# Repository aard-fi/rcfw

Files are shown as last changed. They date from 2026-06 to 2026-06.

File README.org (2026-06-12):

* NoTankS Arduino firmware                                            :TOC_4:
  - [[#introduction][Introduction]]
    - [[#working-features][Working features]]
      - [[#general][General]]
      - [[#notanks][NoTankS]]
    - [[#building][Building]]
    - [[#planned-features][Planned features]]
      - [[#general-1][General]]
      - [[#notanks-1][NoTankS]]
    - [[#required-hardware][Required hardware]]
      - [[#flysky-hardware][Flysky hardware]]
      - [[#elrs-hardware][ELRS hardware]]
  - [[#modified-parts][Modified parts]]
  - [[#rc-hardware][RC hardware]]
    - [[#pistol-grip-elrs-transmitter][Pistol grip ELRS transmitter]]
    - [[#elrs-transmitter][ELRS transmitter]]
    - [[#flysky-transmitter][Flysky transmitter]]
    - [[#6-channel-receivers][6 channel receivers]]
  - [[#arduino-shield][Arduino shield]]
  - [[#manual-wiring][Manual wiring]]
    - [[#led-groups][LED groups]]
    - [[#elrs-receiver-reset][ELRS receiver reset]]
    - [[#models][Models]]
      - [[#arctic-tinyrider][Arctic Tinyrider]]
      - [[#notanks-2][NoTanks]]
      - [[#rc-benchy][RC Benchy]]
  - [[#transmitter-channels][Transmitter channels]]
    - [[#default-channel-mapping-for-radiomaster-mt12][Default channel mapping for Radiomaster MT12]]
    - [[#default-channel-mapping-for-radiomaster-pocket][Default channel mapping for Radiomaster Pocket]]
    - [[#default-channel-mapping-for-flysky-fs-i6][Default channel mapping for Flysky FS-i6]]

** Introduction

This is a variant of my [[https://github.com/bwachter/arctic_tinyrider][Arctic Tinyrider controller firmware]], trying to support multiple models (including the original one) with compile time switches:

- the [[https://www.printables.com/model/114300-arctic-tinyrider-rc-snowmobile][Arctic Tinyrider RC snowmobile]]
- the [[https://www.thingiverse.com/thing:2789361][NoTankS tank]]
- the [[https://www.printables.com/model/34128-rc-benchy][RC Benchy]]

It should also work without changes for any model either just using two motors, ore one motor and one servo for steering - the upcoming model specific details are mostly about LED effects.

You can download pre-built firmware for all supported hardware and feature combinations from the [[https://github.com/aard-fi/rcfw/releases][releases page]] and flash them with [[https://github.com/avrdudes/avrdude][avrdude]] (=avrdude -p atmega328p|atmega4809 -c arduino|jtag2updi -P /dev/ttyS0 -b 115200=) , or follow the build instructions below.

Currently supported are the [[https://store.arduino.cc/products/arduino-nano][Arduino Nano]] and the [[https://store.arduino.cc/products/arduino-nano-every][Arduino Nano Every]] as well as all their clones - especially for the Nano I'd recommend getting a cheap clone (ideally with USB-C) via ebay or aliexpress.

The Every uses the first UART via USB serial, and the second UART via the RX/TX pins (which are used for connecting to the receiver). The older Nano connects its first (and only) UART to both USB serial and the RX/TX pins - so it should be programmed with the rest of the circuit powered down.

This is mostly annoying when actively developing - so for models which only occasionally get updated firmware without active development a generic Nano clone should be sufficient, and way cheaper. At the time of writing a Nano clone (which even has USB C) costs less than 1 EUR, while the original Every goes up to 20 EUR, with clones (which also stick to Micro USB for some reason) selling for roughly 12 EUR. Schematics and PCB layout for a shield offering all connections used by this project are in ./arduino-nano-shield/ - and can be [[https://www.pcbway.com/project/shareproject/rcfw_Arduino_Nano_shield_ea388a65.html][ordered via PCBWay]]. See below for build instructions.

The only other disadvantage of the original Nano for basic models is the lower serial port speed of 115200 - but that should not be an issue for the type of model this firmware tries to support. For ELRS receivers you may have to set their serial speed to 115200 once when using a Nano.

*** Working features
The initial version was written for IBUS receivers - some of the advanced features may not work with CRSF receivers yet.

**** General
- ignition switch: throttle is pinned to zero unless ignition switch is on. This allows somewhat safer handling when not fully switched off. A LED connected to D13 will signal throttle state by blinking (off) or solid light (on).
- throttle and steering (obviously)
- reversing, when supported by the model
- control remapping: a three state switch can be used to change controls. Exact functionality depends on model and transmitter used.
- dynamic speed control: a dial can be used to limit the speed without having to change the throttle curve in the transmitter. In the default setting the transmitter starts with 50% output, and can be set up to 100%. Exact functionality depends on model and transmitter used.
- failsafe requires the ability of the receiver to send sane values when connectivity has been lost. This works well with ELRS receivers, untested with Flysky, though it may be possible with some.
- three groups of LEDs can be used for models in the standard configuration: back/power, front and effect. Any of those LED groups can be set to an arbitrary number of pins from 0 to as many pins are available

Ignition switching, control remapping and dynamic speed control currently can be disabled at compile time to free up channels.

Flysky support will mostly be maintained at the current level, while new features target CRSF. Some rely on ELRS/CRSF behaviour, while others could be enabled somewhat easily for flysky as well. CRSF only features are:

- link detection on startup. The main program will only start running once link has been established
- receiver power cycling. With additional wiring (see below) the receiver can be power cycled on startup. This is recommended, as ELRS receivers go into WiFi configuration mode after some time, and would need manual intervention
- link monitoring with board reset after timeout, configurable at compile time
- remote type detection. With the controls for channel 4 in default position the type of remote (stick or pistol grip) can be auto-detected. This is a compile time setting, which defaults to on.

**** NoTankS
- turning based on accelerating or decelerating one side, depending on the current speed. This also allows turning at zero speed
- curves for low speed cutoff to keep the motors cooler

*** Building

Get the [[https://www.arduino.cc/en/software][Arduino IDE]], and the following libraries:

- the [[https://github.com/arduino-libraries/Servo][servo library]]
- for CRSF use [[https://github.com/AlfredoSystems/AlfredoCRSF][AlfredoCRSF]]
- for IBUS use [[https://github.com/bmellink/IBusBM][IBusBM]]

Configure the correct board (Nano or Nano Every are supported, Every recommended), and go through the defines at the beginning of the file to configure the build for your model and transmitter setup.

Alternatively you can install [[https://docs.arduino.cc/arduino-cli/][arduino-cli]], and use the included Makefile: =make deps= once, and then =make all-variants=, or =make= with the flags you want. See the Makefile for more details.

*** Planned features
**** General
- steering curve adjustment for controllers with two potis
- toggling ESC power supply/board power supply

**** NoTankS
- optimising the steering to result in as little speed change as possible

*** Required hardware

- one Arduino Nano Every
- one receiver
- one radio
- two ESCs with reverse which use the first PWM input value to configure the zero position. It also should be configurable for forward/reverse - most come in forward/reverse/brake configuration, and not all allow omitting the brake. I'm using the 160A variant from [[https://www.aliexpress.com/item/1005006256842555.html][here]].

**** Flysky hardware

Recommendation here is the FS-A8S as receiver, and an AFHDS 2a transmitter, like the FS-i6. When starting new I'd recommend going for ELRS hardware instead, though.

The main drawback of the FS-A8S is the lack of a second iBus - so we can't send custom telemetry data back to the radio. On the plus side it is a tiny receiver, very cheap (roughly 10 EUR), and can output up to 18 channels via iBus. I'm not aware of receivers of a similar size with more than one iBus - other small Flysky receivers just have more connectors for PWM breakout cables, which we don't need as we're controlling that part via the Arduino.

**** ELRS hardware

Any ELRS transmitter should do, if you're looking for recommendations:

- for a pistol grip style one, Radiomaster MT12
- for a traditional drone/plane one, Radiomaster Boxer M2, or if you want to be fancier, the TX16S
- for a small, more portable one, Radiomaster Pocket

For receivers any of the compact (nano) receivers should be fine, from any manufacturer - as far as I'm aware all of them have RX/TX ports for CRSF. Some of the larger ones do not have that - but the tiny ones are easier to stuff into models anyway.

Main drawbock of ELRS is that the receivers are roughly double the price of AFHDS ones - but for that we always have the ability to send telemetry back.

** Modified parts
For some of the models I've modified parts. You can find those in separate repositories:

- [[https://github.com/bwachter/arctic_tinyrider][Arctic Tinyrider]]
- [[https://github.com/bwachter/notanks/][NoTankS]]

** RC hardware

Both throttle curve and trim settings will change the values sent by the transmitter. Currently the assumption is that for our models we can adjust those settings on the Arduino, so adjusted input may be improperly handled - don't use that.

*** Pistol grip ELRS transmitter
With the default setup of steering at channel 1 and throttle at channel two basic control will work out of the box.

Remapping of throttle and steering is not supported as it does not make much sense with that style of transmitter.

The ignition switch is expected on channel 9.

*** ELRS transmitter
This setup is currently untested, but should be working.

The ignition switch is expected on channel 5, which should be one of the two-state switches in the default configuration.

*** Flysky transmitter
At least the FS-i6 requires extra setup for the switches, see the transmitter section below for details.

The ignition switch is expected on channel 7.

*** 6 channel receivers

VRB is currently not used, so to make this work you need to select three features to drop to free up channels, and disable them at compile time. With ELRS receivers supporting at least 16 channels, and all the cheap AFHDS nano receivers supporting 10 support for running building with less than 10 channels may be dropped eventually.

** Arduino shield

The included Arduino shield simplifies the wiring a lot - see the next section if you prefer manual wiring.

#+CAPTION: Three PCB versions, left to right V1, V2 and V2.1
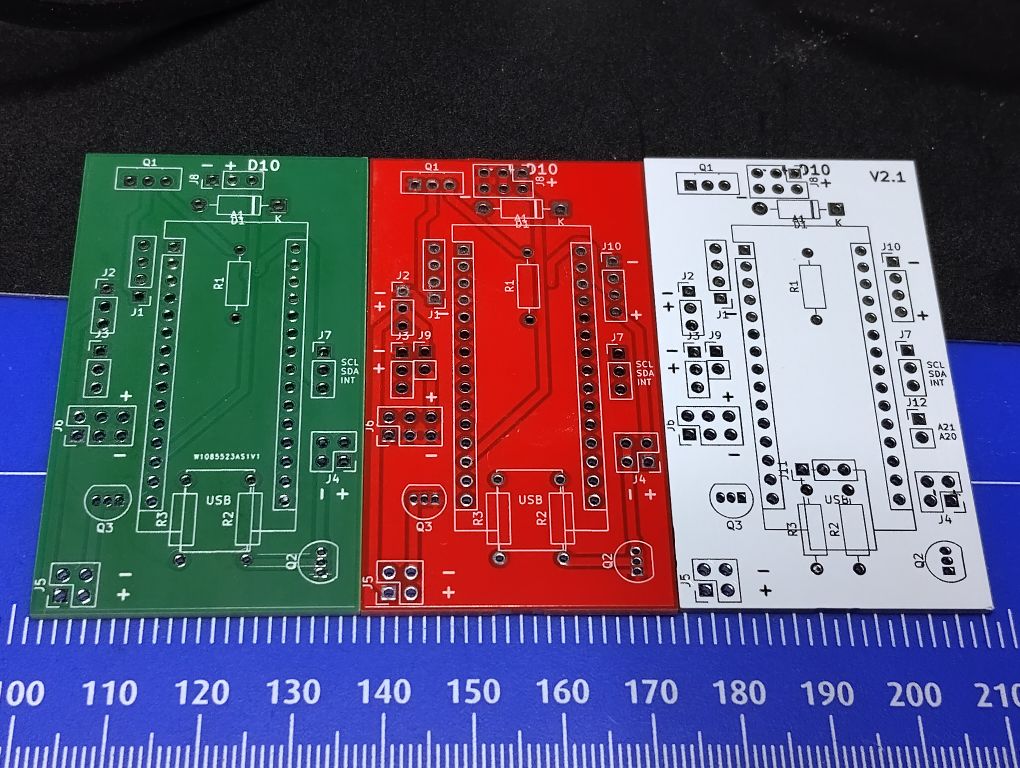
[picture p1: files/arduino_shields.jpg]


If you want the receiver controllable via the Arduino solder a 1kΩ resistor into =R1=, and a  =BD139= or compatible transistor into =Q1=. If you don't need that just bridge pins 1 and 2 of =Q1=.

If you want LEDs solder =2N3904= or compatible transistors into =Q2= and =Q3=, and 4.7kΩ resistors into =R2= and =R3=. If your LEDs are 5V tolerant you can just bridge =R2/R3= instead. Solder pin headers into =J4= and =J5= - each can support two connections.

To prevent the Arduino powering the ESC and motors when only plugged in via USB solder a diode into =D1=. This can be bridged in case you'd rather just be careful, and buy more Arduinos when you mess up.

For the ELRS connector, solder a 4 pin header into =J1=.

For one ESC, solder one 3 pin header into =J2=. This will power the circuit when on battery. For a second ESC, also solder one 3 pin header into =J3=. The power connector from this leads to =J6= - if you want to power extra devices not controlled from the Arduino solder a 6 pin header into that one.

For the servo solder a 3 pin header into =D10=. In case you need two servos, but only one ESC also populate J3, and add a wire bridge from the middle pin of =J3= to the middle pin of =J2= - this will connect the otherwise isolated power pin of =J2/J6=.

To make I²C accessible solder a 3 pin header into =J7=.

The V2 version (included here, but not yet available for order) includes some conveniences for some model:

- the servo header =D10= can be populated with a 3x2 pin header, allowing to plug in two servos. This is useful for the RC benchy to move the steering wheel as well
- a jumper was added between voltage pins of the two ESC headers =J2/J3=. This allows easy power connection for single ESC models, either by jumper or permanent bridge
- a 4 pin header with Arduino pins =D5= and =D6= got added with a common GPS footprint, for use via software serial, though may be useful for extra pins on some other models as well

The V2.1 version adds:

- a three pin header behind the LED resistors over =D11/D12/D13= to allow easy connection of a =74HC595D= module for adding more LEDs
- pin headers on =A20= and =A21= and for future expansions

** Manual wiring

You'll need one power and one ground bar to connect everything to. A quick and dirty variant is getting ready made jumper wires, cut them and then twist end solder the ends together. On the Arduino connect ground and VIN to ground/power bars via a diode to make sure components can't draw power through the Arduino if it is the only thing powered, like during flashing.

The Pins are set up to minimise gaps, soldering three three-pin-headers will cover all pins on one side of the Arduino, while connecting the unused RST pin. On the other side just VIN and D13 need to be populated.

On setups with two or more ESCs make sure to only connect the power pin of one of them.

Nano receivers should have dedicated ground and power connectors either in the header or cable - in that case just connect all of them. For other receivers connect the bus, and take ground and power from any other channel.

The following sections contain tables with the pinouts, with the table colums ordered according to the pinout of the component cables.

IBUS receivers have three pin connectors, and only connect to RX. CRSF receivers have four pin connectors, and also connect to TX. The pinouts are for the Arduino Nano Every - on the Nano use RX/TX instead. Note that flashing on the Nano uses RX/TX, so for that board RX should be disconnected on during flashing.

*** LED groups

The Arduino can tolerate about 20mA per pin, with a total of 200mA. One bright 5mm LED draws roughly 20mA - so three sets of two LEDs should be safe to connect directly. For ad-hoc cabling it is sensible to provide a ground pin to connect to a separate ground bar for additional LEDs. When switching LEDs via a transistor it also makes sense to create a power bar.

With insufficient pins, or more/brighter LEDs they should be wired via a transistor. For a small NPN transistor like the 2N3904 you'd connect the base to the Arduino pin through a 4.7kΩ resistor, emitter to GND, and the LED between VCC and the collector.

The default LED pins are in this table:

|             | Pin 1 | Pin 2 |
|-------------+-------+-------|
| status/back | D13   | D2    |
| front       | D11   | D12   |
| effect      | D4    | D5    |

Pin 2 is only relevant when attaching two power hungry LEDs directly for one specific effect, and may have to be explicitly enabled for a specific model.

If a model doesn't incorporate LEDs one status LED should still be visible for safety reasons. This can either be achieved by mounting the Arduino in a way that the on board LED connected to pin 13 becomes visible, or by connecting an extra LED to pin 13.

When incorporating LEDs into a model the status LEDs should be used as the rear lights.

*** ELRS receiver reset

Pin A7 is configured as digital pin, and pulled high on startup. This allows powering the receiver only when the program is running, and power cycling it as needed.

To use this you'll need a NPN transistor like the BD139. Connect the base to A7 through a 1kΩ resistor, emitter to GND, collector to GND of the receiver, and  of the power in of the receiver to VCC.

*** Models
**** Arctic Tinyrider

|          | GND | 5v | arduino | arduino |
|----------+-----+----+---------+---------|
| ESC      | x   | x  | D3      |         |
| receiver | x   | x  | RX1     | TX1     |
| arduino  | x   | x  |         |         |
| servo    | x   | x  | D10     |         |

**** NoTanks

|           | GND | 5v | arduino | arduino |
|-----------+-----+----+---------+---------|
| left ESC  | x   | x  | D3      |         |
| right ESC | x   | x  | D4      |         |
| receiver  | x   | x  | RX1     | TX1     |
| arduino   | x   | x  |         |         |

**** RC Benchy

|          | GND | 5v | arduino | arduino |
|----------+-----+----+---------+---------|
| ESC      | x   | x  | D3      |         |
| receiver | x   | x  | RX1     | TX1     |
| arduino  | x   | x  |         |         |
| servo    | x   | x  | D10     |         |

** Transmitter channels
This section contains tables about channel setups for all tested transmitters, with information on how to set up additional switches, if needed.

*** Default channel mapping for Radiomaster MT12

| Channel | Trigger  | Type            | Comments                               |
|---------+----------+-----------------+----------------------------------------|
|       1 | wheel    |                 |                                        |
|       2 | throttle |                 |                                        |
|       3 | SA       | switch, 3 state | default 1000                           |
|       4 | SB       | button          | default 1000, starts timer per default |
|       5 | P1       | poti            | default 1500                           |
|       6 | P2       | poti            | default 1500                           |
|       7 | SC       | button, 2 state | default 1000                           |
|       8 | SD       | button, 2 state | default 1000                           |

Note that channel 5 for ELRS is typically a 1 bit channel for arming - and as such the first poti mapped to channel 5 is not ideal. This firmware assumes that it got remapped to channel 5, and the expansion module with the two switches got installed and mapped, leading to the following configuration:

| Channel | Trigger  | Type            | Comments                               |
|---------+----------+-----------------+----------------------------------------|
|       1 | wheel    |                 |                                        |
|       2 | throttle |                 |                                        |
|       3 | SA       | switch, 3 state | default 1000                           |
|       4 | SB       | button          | default 1000, starts timer per default |
|       5 | FL1      | switch, 2 state | default 1000, expansion module (front) |
|       6 | P2       | poti            | default 1500                           |
|       7 | SC       | button, 2 state | default 1000                           |
|       8 | SD       | button, 2 state | default 1000                           |
|       9 | P1       | poti            | default 1500                           |
|      10 | FL2      | switch, 2 state | default 1000, expansion module (back)  |

To configure the expansion module

- go to hardware settings, and set S3/S4 to =switch=
- scroll down, and set =FL1= to =S3=, =FL2= to =S4=, both with =2POS=
- go to model settings, mixes page, and change channel 5 to FL1, add channel 9 with S1, and add channel 10 with FL2

*** Default channel mapping for Radiomaster Pocket

| Channel | Trigger                 | Type            | Comments     |
|---------+-------------------------+-----------------+--------------|
|       1 | right stick, left/right |                 |              |
|       2 | right stick, up/down    |                 |              |
|       3 | left stick, up/down     |                 | default 1000 |
|       4 | left stick, left/right  |                 |              |
|       5 | SA                      | switch, 2 state | default 1000 |
|       6 | SB                      | switch, 3 state | default 1000 |
|       7 | SC                      | switch, 3 state | default 1000 |
|       8 | SD                      | switch, 2 state | default 1000 |
|       9 | SE                      | button, 2 state | default 1000 |
|      10 | SI                      | poti            | default 1000 |

*** Default channel mapping for Flysky FS-i6

| Channel | Trigger                 | Type            | Comments     |
|---------+-------------------------+-----------------+--------------|
|       1 | right stick, left/right |                 |              |
|       2 | right stick, up/down    |                 |              |
|       3 | left stick, up/down     |                 | default 1000 |
|       4 | left stick, left/right  |                 |              |
|       5 | VRA                     | poti            | default 1000 |
|       6 | VRB                     | poti            | default 1000 |
|       7 | SWA                     | switch, 3 state | default 1000 |
|       8 | SWB                     | switch, 2 state | default 1000 |
|       9 | SWC                     | switch, 2 state | default 1000 |
|      10 | SWD                     | switch          | default 1000 |

VRA/VRB are configured on channels 5/6 per default in 'aux channel setup', while the switches are not assigned.

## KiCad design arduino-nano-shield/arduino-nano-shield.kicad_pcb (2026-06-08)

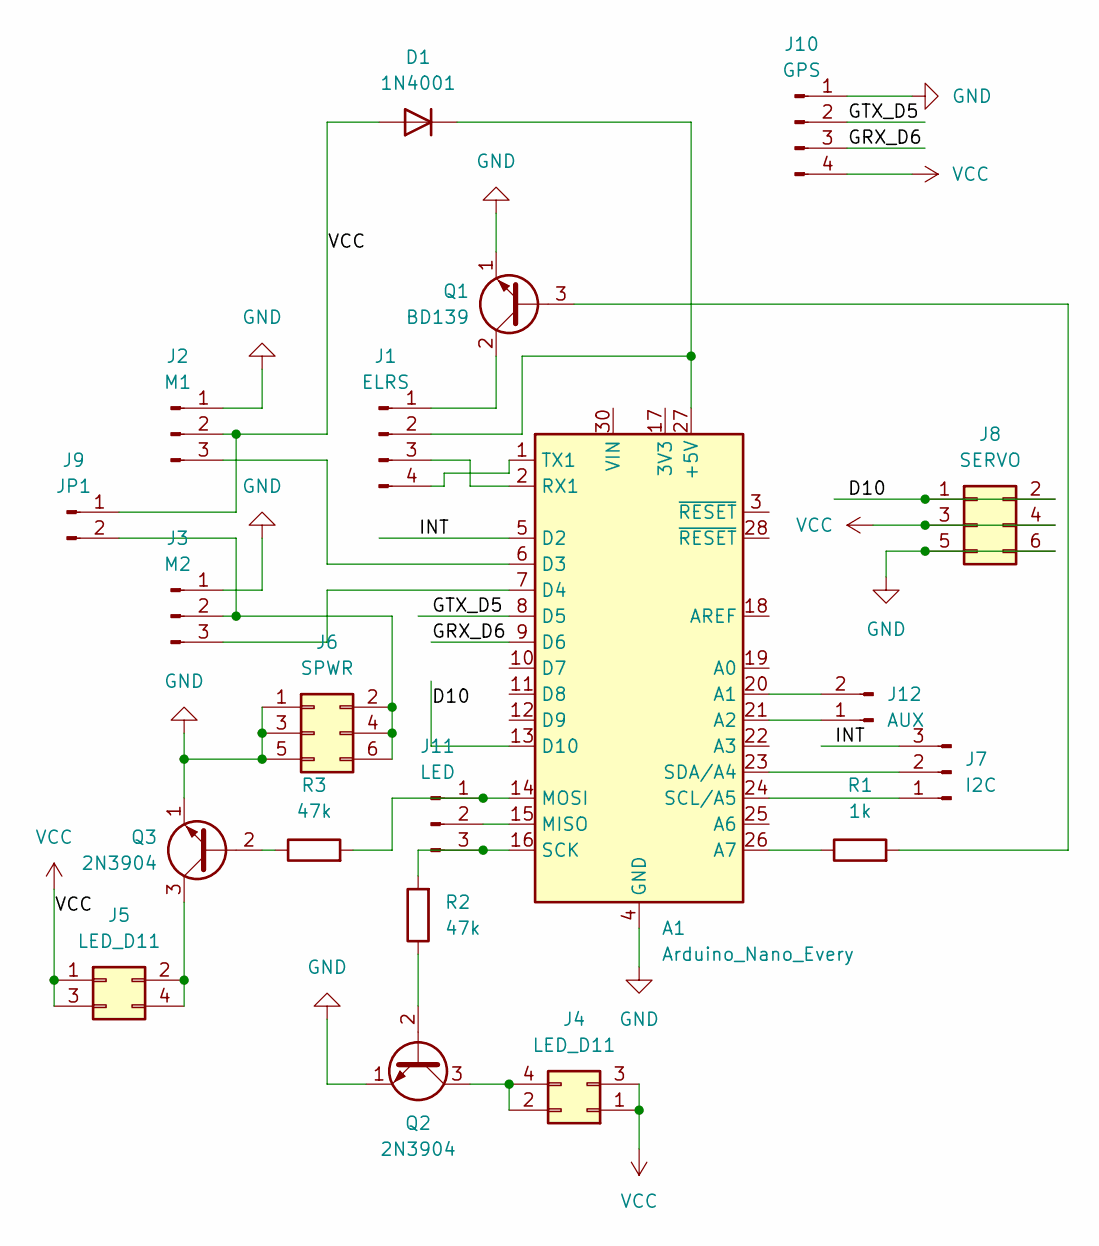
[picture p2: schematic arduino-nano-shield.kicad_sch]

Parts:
A1: Arduino_Nano_Every; Arduino_Nano
D1: 1N4001; D_DO-41_SOD81_P10.16mm_Horizontal
J1: ELRS; PinHeader_1x04_P2.54mm_Vertical
J2: M1; PinHeader_1x03_P2.54mm_Vertical
J3: M2; PinHeader_1x03_P2.54mm_Vertical
J4, J5: LED_D11; PinHeader_2x02_P2.54mm_Vertical
J6: SPWR; PinHeader_2x03_P2.54mm_Vertical
J7: I2C; PinHeader_1x03_P2.54mm_Vertical
J8: SERVO; PinHeader_2x03_P2.54mm_Vertical
J9: JP1; PinHeader_1x02_P2.54mm_Vertical
J10: GPS; PinHeader_1x04_P2.54mm_Vertical
J11: LED; PinHeader_1x03_P2.54mm_Vertical
J12: AUX; PinHeader_1x02_P2.54mm_Vertical
Q1: BD139; TO-126-3_Vertical
Q2, Q3: 2N3904; TO-92_Inline
R1: 1k; R_Axial_DIN0207_L6.3mm_D2.5mm_P10.16mm_Horizontal
R2, R3: 47k; R_Axial_DIN0207_L6.3mm_D2.5mm_P10.16mm_Horizontal

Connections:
/D10: A1.13 (D10), J8.1, J8.2
/GRX_D6: A1.9 (D6), J10.3
/GTX_D5: A1.8 (D5), J10.2
/INT: A1.5 (D2), J7.3
GND: A1.4 (GND), A1.29 (GND), J2.1, J3.1, J6.1, J6.3, J6.5, J8.5, J8.6, J10.1, Q1.1 (E), Q2.1 (E), Q3.1 (E)
unnamed: A1.27 (+5V), D1.1 (K), J1.2
unnamed: A1.20 (A1), J12.2
unnamed: A1.21 (A2), J12.1
unnamed: A1.26 (A7), R1.1
unnamed: A1.6 (D3), J2.3
unnamed: A1.7 (D4), J3.3
unnamed: A1.15 (MISO), J11.2
unnamed: A1.14 (MOSI), J11.1, R3.2
unnamed: A1.2 (RX1), J1.3
unnamed: A1.16 (SCK), J11.3, R2.2
unnamed: A1.24 (SCL/A5), J7.1
unnamed: A1.23 (SDA/A4), J7.2
unnamed: A1.1 (TX1), J1.4
unnamed: J1.1, Q1.2 (C)
unnamed: J3.2, J6.2, J6.4, J6.6, J9.2
unnamed: J4.2, J4.4, Q2.3 (C)
unnamed: J5.2, J5.4, Q3.3 (C)
unnamed: Q1.3 (B), R1.2
unnamed: Q2.2 (B), R2.1
unnamed: Q3.2 (B), R3.1
VCC: D1.2 (A), J2.2, J4.1, J4.3, J5.1, J5.3, J8.3, J8.4, J9.1, J10.4

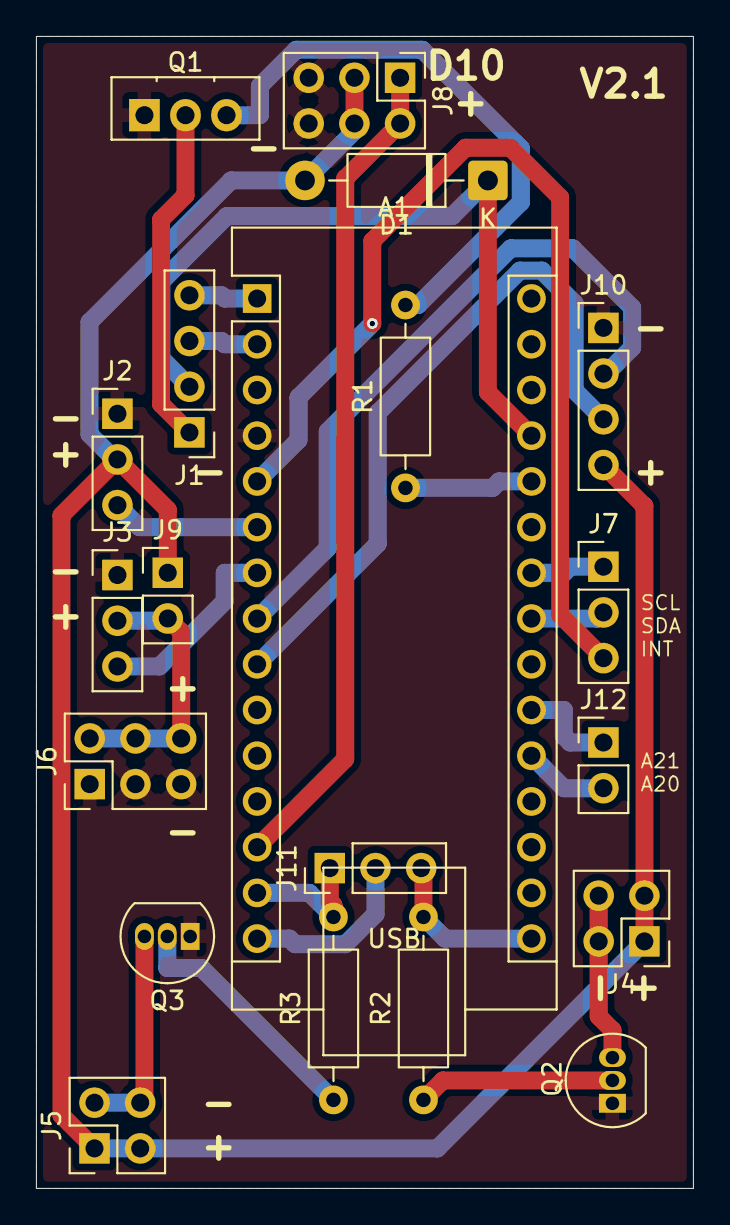
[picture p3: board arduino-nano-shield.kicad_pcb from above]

Board: 2 copper layers, 36.5 x 64.0 mm, 20 parts (0 on the bottom side), 26 nets.

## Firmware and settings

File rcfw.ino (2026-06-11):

// See LICENSE.txt or https://creativecommons.org/licenses/by-nc-sa/4.0/
#include <Servo.h>
#include <avr/wdt.h>

#define SNOW_MOBILE 1
#define RC_BENCHY 2
#define NOTANK 3

#define LED_MODE_DIRECT 1
#define LED_MODE_74HC595D 2
#define LED_MODE_ADDRESSABLE 3

// set this to the LED mode you're using from above list
// when not using any LEDs any value here is fine
#define LED_MODE LED_MODE_74HC595D

// set this to the model you're using from above list
#ifndef RC_MODEL
#define RC_MODEL NOTANK
#endif

struct channel_mapping {
    int control_channel;
    int ignition_channel;
    int effect_channel;
    int speed_channel;
};

// if we have no idea what the remote control is just disable
// all the fancy extra channels
const channel_mapping default_mapping = {
  .control_channel = -1,
  .ignition_channel = -1,
  .effect_channel = -1,
  .speed_channel = -1
};

const channel_mapping flysky_st_mapping = {
  .control_channel = 8,
  .ignition_channel = 7,
  .effect_channel = 6,
  .speed_channel = 5
};

const channel_mapping radiomaster_st_mapping = {
  .control_channel = 7,
  .ignition_channel = 5,
  .effect_channel = -1,
  .speed_channel = 10
};

const channel_mapping radiomaster_pg_mapping = {
  .control_channel = -1,
  .ignition_channel = 5,
  .effect_channel = -1,
  .speed_channel = 6
};

// I do not have a pistol grip FlySky transmitter - the first entry is a placeholder in case someone
// wants to contribute that.
//
// The generic manufacturer types are used for type auto detection. For the Radiomaster ones we can
// use channel 4 to check the type: PG has it at 1000 as default, while stick has it at 1500.
#define FLYSKY_PG 1
#define FLYSKY_ST 2
#define FLYSKY 3
#define RADIOMASTER_PG 4
#define RADIOMASTER_ST 5
#define RADIOMASTER 6

// select the type of transmitter from above list. For pistol grip style transmitters
// the first two channels should be the same, no matter the manufacturer. For stick style
// transmitters the first four channels should be the same - so basic functionality should
// work by just selecting a matching type.
//
// for extra functionality involving the switches and potis receiver specific configuration
// may be required
#ifndef TX_TYPE
#define TX_TYPE RADIOMASTER
#endif

// this must match the configured speed in the receiver
// if the connection does not work double check that the receiver is configured
// correctly. This is particularly important on the original Nano, which can
// only reliably sustain serial speeds of up to 115200 - for other boards our
// default should match the receiver default.
#ifdef ARDUINO_AVR_NANO
#define CRSF_SPEED 115200
#else
#define CRSF_SPEED 420000
#endif

// set this for logging complete channel status table (CRSF only)
//#define DEBUG_CHANNELS 1

// remove this to skip all debug messages. Note that the Nano already
// doesn't log due to the single serial port.
#define DEBUG_MESSAGES 1

/*
 The further you go down the defines the less likely you should
 want to change something.

 PWM motor ranges are based on the servo library, ranging from 0 to 180 - not
 the native 0-255 of Arduino PWM (which is a wrong frequency)..
*/

// this is the slowest supported motor speed - everything lower and we'll
// disable the motor to avoid them burning out
#define PWM_CUTOFF 10

// the digital pin the motor is attached to
#if RC_MODEL == NOTANK
#define MOTOR_PIN_LEFT 3
#define MOTOR_PIN_RIGHT 4
#elif RC_MODEL == RC_BENCHY
#define MOTOR_PIN 3
#define SERVO_PIN 10
#elif RC_MODEL == SNOW_MOBILE
#define MOTOR_PIN 3
#define SERVO_PIN 10
#endif

// Helpers for LED array definitions.  In direct mode only LED() is usable.
#define LED(n)     (n)           // single-colour LED on pin or output n
#define RGB(n)     (-(n) - 2)    // RGB on outputs n(R), n+1(G), n+2(B). n >= 0.
#define RGBW(n)    (-(n) - 1002) // RGBW on outputs n(R), n+1(G), n+2(B), n+3(W). n >= 0.

// LED definitions must end with -1 as end of array marker to support
// variable amounts of LED pins depending on model.
//
// The power LEDs also serve as rear lights.
//
// Encoding (see also LED(), RGB(), RGBW() macros):
//   positive value (0, 1, 2 …)   = single-colour LED on that pin/index.
//   negative value -2 … -999     = RGB LED.  Base index = abs(value) - 2.
//   negative value -1002 …       = RGBW LED. Base index = abs(value) - 1002.
//   -1                           = end of array.
// Examples:    5  -> single LED on pin/index 5
//             -2  -> RGB on pins/indices 0(R), 1(G), 2(B)
//             -5  -> RGB on pins/indices 3(R), 4(G), 5(B)
//          -1002  -> RGBW on pins/indices 0(R), 1(G), 2(B), 3(W)
//          -1005  -> RGBW on pins/indices 3(R), 4(G), 5(B), 6(W)
#if LED_MODE == LED_MODE_DIRECT
#define POWER_LEDS {2,13,-1}
#if RC_MODEL == NOTANK
#define POWER_LEDS {13,-1}
#define FRONT_LEDS {11,-1}
#define EFFECT_LEDS {-1}
#else
#define FRONT_LEDS {11,12,-1}
#define EFFECT_LEDS {4,5,-1}
#endif

#elif LED_MODE == LED_MODE_74HC595D
const int data_pin = 11; // LDSI
const int latch_pin = 12; // LDSTR
const int clock_pin = 13; // LDSCK

// LED indices in the 24-bit shift register chain (3x 74HC595D).
// Each logical LED group is tied to one physical chip for clean wiring:
//   Chip 1 (outputs 0-7):   Rear / power LEDs
//   Chip 2 (outputs 8-15):  Front LEDs
//   Chip 3 (outputs 16-23): Effect LEDs
//
// Use LED() for single-colour outputs, RGB() for RGB triples, RGBW() for RGBW.
// RGB() or RGBW() definitions still work with on/off commands, as those trigger
// all possible outputs.
#define POWER_LEDS  { RGB(0), -1 }   // outputs 0(R), 1(G), 2(B)  – first chip
#define FRONT_LEDS  { RGB(8), -1 }   // outputs 8(R), 9(G), 10(B) – second chip
#define EFFECT_LEDS { LED(16), -1 }  // output 16                 – third chip

#elif LED_MODE == LED_MODE_ADDRESSABLE
// placeholder for addressable LED pin/index definitions
#endif

/*
This is the default speed curve for dynamic speed adjustment, which allows adjusting from
0% to 100%, on a model which does have reversing. Adjusting it is not tested, though, and
may need somewhat more complicated speed calculations: currently models which support
speed adjustment just start at min-45 and max-45, and add those speed adjustments in, which
expands to the whole range.
*/
#define SPEED_MIN -45
#define SPEED_MAX 45

// The receiver should be connected to this pin via a NPN transistor to enable
// power cycling it when the Arduino restarts. With ELRS receivers and binding
// phrases this allows easy switching of controllers during play without having
// to touch the model
#define POWER_PIN_RCV A7
#define POWER_PIN A6

// time LED should remain in a specific status. This is per loop - so
// take LOOP_DELAY into account as well.
#define LED_DELAY 10
// slightly delays the loop to allow time for mechanical elements to
// move, at cost of slight input delay.
#define LOOP_DELAY 20

#define DEBUG_DELAY 10

#define PWM_MIN 0
#define PWM_MID 90
#define PWM_MAX 180

#define PWM_STOP 90

#define STEER_MIN 0
#define STEER_MID 90
#define STEER_MAX 180

// with trim the values sent by the transmitter might be over/under this range,
// but this is good enough for now
#define RX_MIN 1000
#define RX_MID 1500
#define RX_MAX 2000

#define RX_TOLERANCE 30

#define TX_IBUS 1
#define TX_CRSF 2

#if TX_TYPE <= FLYSKY
#define SERIAL_PROTOCOL TX_IBUS
#else
#define SERIAL_PROTOCOL TX_CRSF
#endif

#if SERIAL_PROTOCOL == TX_CRSF
// defines how many loop cycles we wait when link has been lost before
// resetting.
#define LINK_DOWN_DELAY 1000
#endif

#if SERIAL_PROTOCOL == TX_IBUS
#include <IBusBM.h>
IBusBM IBus;
#elif SERIAL_PROTOCOL == TX_CRSF
#include <AlfredoCRSF.h>
AlfredoCRSF crsf;
#endif

#if RC_MODEL == NOTANK
Servo motor_left;
Servo motor_right;
#elif RC_MODEL == RC_BENCHY
Servo motor;
Servo steering;
#elif RC_MODEL == SNOW_MOBILE
Servo motor;
Servo steering;
#endif
int ignition=RX_MIN;
int led_state=0;
int debug_state=0;
#ifdef LINK_DOWN_DELAY
int linkdown_state=0;
#endif
int throttle_channel;
int steering_channel;

int power_leds[]=POWER_LEDS;
int front_leds[]=FRONT_LEDS;
int effect_leds[]=EFFECT_LEDS;

enum led_effects{
  led_off   = 0x00,
  led_r     = 0x01,  // bit 0
  led_g     = 0x02,  // bit 1
  led_b     = 0x04,  // bit 2
  led_w     = 0x08,  // bit 3
  led_on    = 0x0F,  // r | g | b | w
  led_cycle = 0x10,  // bit 4 – OR with any colour for blink
};

channel_mapping get_tx_mapping(int type){
  switch(type){
    case FLYSKY_ST: return flysky_st_mapping;
    case RADIOMASTER_ST: return radiomaster_st_mapping;
    case RADIOMASTER_PG: return radiomaster_pg_mapping;
    default: return default_mapping;
  }
}

int current_tx = TX_TYPE;
channel_mapping tx_mapping = get_tx_mapping(current_tx);

void setup_controls(){
  int controls;
  if (tx_mapping.control_channel >= 1){
#if SERIAL_PROTOCOL == TX_IBUS
    controls = IBus.readChannel(tx_mapping.control_channel-1);
#elif SERIAL_PROTOCOL == TX_CRSF
    controls = crsf.getChannel(tx_mapping.control_channel);
#endif
  } else {
    controls = RX_MIN;
  }

  if (controls <= RX_MIN)
    controls = RX_MIN;

  /*
     For IBUS channel numbers are C indexes, i.e., one less than your transmitter
     shows you. For CRSF the channel numbers match the numbers on the transmitter.

     We adjust the numbers when reading from ibus channels, so we can use the actual
     channel numbers here - and avoid having duplicate defines for IBUS/CRSF
  */
#if RC_MODEL == NOTANK
  // throttle is only supported right due to support for reversing
  if (controls == RX_MID){
    // throttle right, steering left
    throttle_channel=2;
    steering_channel=4;
  } else {
    // throttle and steering right
    steering_channel=1;
    throttle_channel=2;
  }
#else
  if (controls == RX_MID){
    // throttle right, steering left
    throttle_channel=2;
    steering_channel=4;
  } else if (controls == RX_MAX) {
    // throttle left, steering right
    steering_channel=1;
    throttle_channel=3;
  } else {
    // throttle and steering right
    steering_channel=1;
    throttle_channel=2;
  }
#endif
}

#if LED_MODE == LED_MODE_74HC595D
uint32_t sr_state = 0;

void shift_out_state(){
  digitalWrite(latch_pin, LOW);
  // For chained 74HC595Ds, shift the last chip's byte first so it propagates down the chain.
  // The last byte shifted ends up in the first chip connected to the Arduino.
  shiftOut(data_pin, clock_pin, MSBFIRST, (sr_state >> 16) & 0xFF);
  shiftOut(data_pin, clock_pin, MSBFIRST, (sr_state >> 8) & 0xFF);
  shiftOut(data_pin, clock_pin, MSBFIRST, sr_state & 0xFF);
  digitalWrite(latch_pin, HIGH);
}
#endif

void set_led(int leds[], int cycle, int effect){
  bool do_cycle = effect & led_cycle;
  uint8_t color = effect & led_on;

  // backward compat: bare led_cycle without colour means cycle full on/off
  if (do_cycle && color == 0)
    color = led_on;

  // apply cycle timing: negative cycle value = OFF phase
  if (do_cycle && cycle < 0)
    color = led_off;

  int i=0;
  while (leds[i] != -1){
    int idx = leds[i];
    bool is_rgbw = (idx <= -1000);
    bool is_rgb  = (idx < -1) && !is_rgbw;
    if (is_rgbw)      idx = -idx - 1002;
    else if (is_rgb)  idx = -idx - 2;

#if LED_MODE == LED_MODE_DIRECT
    // direct mode does not support RGB or RGBW (not enough pins), so any
    // non-zero colour falls back to simple ON.
    digitalWrite(idx, color ? HIGH : LOW);

#elif LED_MODE == LED_MODE_74HC595D
    if (is_rgb){
      uint32_t mask = 0;
      if (color & led_r) mask |= (1UL << idx);
      if (color & led_g) mask |= (1UL << (idx+1));
      if (color & led_b) mask |= (1UL << (idx+2));
      uint32_t clear_mask = (1UL << idx) | (1UL << (idx+1)) | (1UL << (idx+2));
      sr_state = (sr_state & ~clear_mask) | mask;
    } else if (is_rgbw){
      uint32_t mask = 0;
      if (color & led_r) mask |= (1UL << idx);
      if (color & led_g) mask |= (1UL << (idx+1));
      if (color & led_b) mask |= (1UL << (idx+2));
      if (color & led_w) mask |= (1UL << (idx+3));
      uint32_t clear_mask = (1UL << idx) | (1UL << (idx+1))
                          | (1UL << (idx+2)) | (1UL << (idx+3));
      sr_state = (sr_state & ~clear_mask) | mask;
    } else {
      uint32_t mask = 1UL << idx;
      if (color)
        sr_state |= mask;
      else
        sr_state &= ~mask;
    }

#elif LED_MODE == LED_MODE_ADDRESSABLE
    // placeholder: colour bits map directly to RGB components
#endif
    i++;
  }
#if LED_MODE == LED_MODE_74HC595D
  shift_out_state();
#endif
}

void wdt_reset_delay(int d){
  for (int i=1; i<=d; i+=10){
    wdt_reset();
    delay(10);
  }
}

void setup_led(int leds[]){
#if LED_MODE == LED_MODE_DIRECT
  int i=0;
  while (leds[i] != -1){
    pinMode(leds[i], OUTPUT);
    i++;
  }
#endif
}

void setup() {
  wdt_disable();
#if LED_MODE == LED_MODE_DIRECT
  setup_led(power_leds);
  setup_led(effect_leds);
  setup_led(front_leds);
#elif LED_MODE == LED_MODE_74HC595D
  pinMode(data_pin, OUTPUT);
  pinMode(latch_pin, OUTPUT);
  pinMode(clock_pin, OUTPUT);
#elif LED_MODE == LED_MODE_ADDRESSABLE
  // addressable LED setup will go here
#endif

  set_led(power_leds, 0, led_on);
  set_led(front_leds, 0, led_on);
  set_led(effect_leds, 0, led_on);

  pinMode(POWER_PIN_RCV, OUTPUT);
  digitalWrite(POWER_PIN_RCV, LOW);
  delay(500);
  digitalWrite(POWER_PIN_RCV, HIGH);

  pinMode(POWER_PIN, OUTPUT);
  digitalWrite(POWER_PIN, LOW);
  delay(500);
  digitalWrite(POWER_PIN, HIGH);

#ifdef ARDUINO_AVR_NANO_EVERY
#ifdef DEBUG_MESSAGES
#define debug_print if (debug_state == 0) Serial.print
#define debug_println if (debug_state == 0) Serial.println
#else
#define debug_print(...) ((void)0)
#define debug_println(...) ((void)0)
#endif
  Serial.begin(115200);
  // on the Every the internal timer doesn't work - so disable it here,
  // and manually call loop() in the loop
#if SERIAL_PROTOCOL == TX_IBUS
  IBus.begin(Serial1,IBUSBM_NOTIMER);
#elif SERIAL_PROTOCOL == TX_CRSF
  Serial1.begin(CRSF_SPEED);
  crsf.begin(Serial1);
  debug_println("Setting up CRSF on port 1");
#endif
#elif ARDUINO_AVR_NANO
#if SERIAL_PROTOCOL == TX_IBUS
  IBus.begin(Serial,IBUSBM_NOTIMER);
#elif SERIAL_PROTOCOL == TX_CRSF
  Serial.begin(CRSF_SPEED);
  crsf.begin(Serial);
#endif
  #warning Building for Nano disables debug output
#define debug_print(...) ((void)0)
#define debug_println(...) ((void)0)
#else
  #error Build running on unsupported board
#endif

  // the calls here calibrate the neutral position for the ESC
#if RC_MODEL == NOTANK
  motor_left.attach(MOTOR_PIN_LEFT, RX_MIN, RX_MAX);
  motor_left.write(PWM_STOP);
  motor_right.attach(MOTOR_PIN_RIGHT, RX_MIN, RX_MAX);
  motor_right.write(PWM_STOP);

#elif RC_MODEL == RC_BENCHY
  motor.attach(MOTOR_PIN, RX_MIN, RX_MAX);
  motor.write(PWM_STOP);

  steering.attach(SERVO_PIN);
  steering.write(STEER_MAX);
  delay(1);
  steering.write(STEER_MIN);
  delay(1);
  steering.write(STEER_MID);
#elif RC_MODEL == SNOW_MOBILE
  motor.attach(MOTOR_PIN, RX_MIN, RX_MAX);
  motor.write(PWM_STOP);
  steering.attach(SERVO_PIN);
  steering.write(STEER_MAX);
  delay(1);
  steering.write(STEER_MIN);
  delay(1);
  steering.write(STEER_MID);
#endif

  // add some delay in case something still needs to settle, and then
  // switch lights off to show we're done with the first init phase
  delay(1000);
  set_led(power_leds, 0, led_off);
  set_led(front_leds, 0, led_off);
  set_led(effect_leds, 0, led_off);

  wdt_enable(WDTO_2S);
  wdt_reset();

#if SERIAL_PROTOCOL == TX_CRSF
  crsf.update();

  int ch4 = crsf.getChannel(4);
  int loop = 0;
  while(ch4 <= RX_MIN - RX_TOLERANCE - 1){
    set_led(power_leds, 0, led_on);
    debug_print(ch4);
    debug_print(" waiting for CRSF transmitter...");
    debug_println(loop);
    loop++;
    wdt_reset_delay(100);
    crsf.update();
    ch4 = crsf.getChannel(4);
    if (loop <= 60){
      set_led(power_leds, 0, led_off);
      wdt_reset_delay(400);
    } else {
      debug_println("Timout waiting for CRSF transmitter.");
      while(true){
        set_led(power_leds, 0, led_off);
        delay(20);
        set_led(power_leds, 0, led_on);
        delay(20);
      }
    }
  }

#if TX_TYPE == RADIOMASTER
  debug_println("");
  debug_print("Channel 4: ");
  debug_println(ch4);
  if (ch4 >= RX_MIN - RX_TOLERANCE && ch4 <= RX_MIN + RX_TOLERANCE){
    current_tx = RADIOMASTER_PG;
  } else if (ch4 >= RX_MID - RX_TOLERANCE && ch4 <= RX_MID + RX_TOLERANCE){
    current_tx = RADIOMASTER_ST;
  } else {
    debug_print("Unable to identify remote type");
    delay(10000);
  }

  // this relies on the model restarting to detect remote control changes.
  // if we want to do that during runtime that needs to move to setup_controls
  tx_mapping = get_tx_mapping(current_tx);
#endif
#endif

  setup_controls();
}
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
void loop() {
  wdt_reset();

  debug_print("tx: ");
  debug_print(current_tx);
  debug_print(" ");

#if SERIAL_PROTOCOL == TX_IBUS
  IBus.loop();
#elif SERIAL_PROTOCOL == TX_CRSF
  crsf.update();
#endif
  if (led_state >= LED_DELAY)
    led_state = LED_DELAY*-1;
  led_state++;

#ifdef LINK_DOWN_DELAY
  if (crsf.isLinkUp() == false){
    ignition = RX_MIN;
    debug_print(" link down: ");
    debug_print(linkdown_state);
    debug_print(" ");
    if (linkdown_state >= LINK_DOWN_DELAY)
      delay(5000);

    linkdown_state++;
  } else
      linkdown_state = 0;
#endif

  setup_controls();

  if (tx_mapping.ignition_channel >= 1){
#if SERIAL_PROTOCOL == TX_IBUS
    ignition = IBus.readChannel(tx_mapping.ignition_channel-1);
#elif SERIAL_PROTOCOL == TX_CRSF
    if (crsf.isLinkUp() == true)
      ignition = crsf.getChannel(tx_mapping.ignition_channel);
#endif
  }

  debug_print(" Ignition(");
  debug_print(tx_mapping.ignition_channel);
  debug_print("): ");
  debug_print(ignition);
  debug_print(" ");

  set_led(front_leds, led_state, led_on);

  if (ignition != RX_MAX){
#if RC_MODEL == NOTANK
    motor_left.write(PWM_STOP);
    motor_right.write(PWM_STOP);
#elif RC_MODEL == RC_BENCHY
    motor.write(PWM_STOP);
#endif

    set_led(power_leds, led_state, led_cycle);
  } else {
    int steer;

#if SERIAL_PROTOCOL == TX_IBUS
    steer = IBus.readChannel(steering_channel-1);
#elif SERIAL_PROTOCOL == TX_CRSF
    steer = crsf.getChannel(steering_channel);
#endif

    debug_print("Steer: ");
    debug_print(steer);
    int steer_pwm=0;

    steer = rx_adjust(steer, RX_MID);

    if (steer >= RX_MIN and steer <= RX_MAX){
      steer_pwm = map(steer, RX_MIN, RX_MAX, STEER_MIN, STEER_MAX);
      debug_print(" pwm ");
      debug_print(steer_pwm);
    }

    set_led(power_leds, led_state, led_on);
    int throttle;
#if SERIAL_PROTOCOL == TX_IBUS
    throttle = IBus.readChannel(throttle_channel-1);
#elif SERIAL_PROTOCOL == TX_CRSF
    throttle = crsf.getChannel(throttle_channel);
#endif

    // TODO, for the snow mobile we probably want a different fallback
    throttle = rx_adjust(throttle, RX_MID);

    debug_print(" Throttle: ");
    debug_print(throttle);

    // TODO: max speed is currently ignored, as that'd only apply to maximum
    //       forward speed. Should be applied to both forward/reverse. But
    //       also might be dropped completely - motor seems to be correctly
    //       sized here, so might not be needed at all.
    int throttle_max_raw = 1500;
    if (tx_mapping.speed_channel >= 1){
#if SERIAL_PROTOCOL == TX_IBUS
      throttle_max_raw = IBus.readChannel(tx_mapping.speed_channel-1);
#elif SERIAL_PROTOCOL == TX_CRSF
      throttle_max_raw = crsf.getChannel(tx_mapping.speed_channel);
#endif
    }


    int throttle_max = map(throttle_max_raw, RX_MIN, RX_MAX, SPEED_MIN, SPEED_MAX);
    int pwm_adjusted = 0;

    // to compensate for wonky remote midpoint adjust +- 10
    if (throttle >= RX_MID+10)
      pwm_adjusted = map(throttle, RX_MID, RX_MAX, PWM_MID+PWM_CUTOFF, PWM_MAX);
    else if (throttle <= RX_MID-10)
      pwm_adjusted = map(throttle, RX_MID, RX_MIN, PWM_MID-PWM_CUTOFF, PWM_MIN);
    else
      pwm_adjusted = PWM_STOP;

    debug_print(" ");
    debug_print(pwm_adjusted);

    controls(pwm_adjusted, steer_pwm, throttle_max);
  }

#if SERIAL_PROTOCOL == TX_CRSF
  debug_print(" | ");
#ifdef DEBUG_CHANNELS
  print_channels();
#endif
#endif

  debug_println();

  debug_state++;
  if (debug_state >= DEBUG_DELAY)
    debug_state = 0;

  delay(LOOP_DELAY);
}

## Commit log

2025-07-16 refactor: prepare for supporting various models from one firmware
    [notanks_v1_track.stl, notanks_v2_track_insert.stl, track.scad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]
2025-07-16 refactor: Add support for multiple RC models
    Introduced support for controlling different RC models
    by defining model-specific configurations and behaviors in the
    rcfw.ino file. The code now uses preprocessor directives to
    switch between configurations for NOTANK and RC_BENCHY models.
    For the NOTANK model, added separate steering controls for
    left and right motor pins, including a new steering logic
    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
2025-07-16 feat: Add conditional debug output based on board type
    This commit introduces conditional debug output functionality based on
    the type of board the code is being compiled for, enhancing flexibility
    and maintainability:
    - Added preprocessor directives to define debug output functions
    (`debug_print` and `debug_println`) that either map to `Serial.print`
    and `Serial.println` or do nothing, depending on the board type.
    - For `ARDUINO_AVR_NANO_EVERY`, debug output is enabled, using `Serial`
    for logging.
    - For `ARDUINO_AVR_NANO`, debug output is disabled entirely, issuing
    a warning about debug output being unavailable.
    - An error directive ensures that an unsupported board type will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
    [rcfw.ino]
2025-07-16 refactor: Add support for snow mobile RC model
    Added a new RC model configuration for a snow mobile. This includes
    setting specific motor and servo pins. Defined arrays for front and
    effect LEDs, ensuring compatibility with the current setup. Updated
    steering and motor control logic in `setup` and `controls` to handle
    the snow mobile model. Adjusted `setup_controls` function to correctly
    map throttle and steering channels. Each configuration comes with a
    distinct set of servo initialization steps and conditional logic for
    handling the different models.
    This is untested yet, just an attempt to not lose the original snow
    mobile code.
    [rcfw.ino]
2025-07-16 feat: Add CRSF protocol support in control logic
    This commit adds support for the CRSF protocol in the control
    logic of the "rcfw.ino" file. The code now conditionally includes
    either the IBusBM or AlfredoCRSF library based on the SERIAL_PROTOCOL
    define.
    Changes include:
    - Added new `#define` for CRSF and conditional logic to switch
    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
2025-07-16 docs: Expand hardware and model support in README
    The README has been updated to provide clearer guidance on supported
    models and hardware. Sections on Flysky and ELRS hardware have been
    added under 'Required hardware.' This update introduces the developer's
    attempt to support multiple models including the Arctic Tinyrider,
    NoTankS tank, and RC Benchy with compile-time switches. The hardware
    list now differentiates between Flysky and ELRS hardware with
    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
2025-07-17 docs: Update README with new wiring and setup details
    Expanded README to include more comprehensive wiring and setup
    instructions for different models supported by the NoTankS Arduino
    firmware. Detailed pinout tables have been added for Arctic Tinyrider,
    NoTanks, and RC Benchy, along with information on how to support
    LEDs in future updates. Clarified transmitter setup and the
    configurations necessary for different types of transmitters,
    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
2025-07-17 refactor: Define constants for RX boundary values
    The commit refactors the code by replacing hardcoded RX boundary values
    such as 1000, 1500, and 2000 with defined constants RX_MIN, RX_MID,
    and RX_MAX. This improves readability and maintainability.
    - Introduced a new constant RX_TOLERANCE to handle slight deviations
    from RX_MIN and RX_MAX, improving stability in signal handling.
    - Renamed the function printChannels to print_channels to follow
    consistent naming conventions.
    - Simplified the controls function by removing the unnecessary steer
    parameter across multiple RC models.
    - Added a new function, rx_adjust, which ensures that values remain
    within the specified RX limits, adding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
    [rcfw.ino]
2025-07-18 refactor: Enhance transmitter type configuration
    Implemented refactor of the transmitter configuration logic to support
    different types of transmitters consistently, including FlySky and
    Radiomaster models in both pistol grip and stick styles. This update
    organizes the code to define the transmitter type (`TX_TYPE`) and
    selects appropriate channel mappings, ensuring correct communication
    protocols (i.e., IBUS or CRSF).
    Highlights include:
    - Introduced transmitter and serial protocol definitions for different
    types of controllers.
    - Adjusted channel definitions and mappings based on transmitter types.
    - Added compile-time debug messages that can be enabled or disabled.
    - Improved handling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
    [rcfw.ino]
2025-07-18 docs: Update README with building and transmitter info
    Added detailed instructions for building the project using the
    Arduino IDE, including necessary libraries and board configuration.
    Modified the section on RC hardware to replace 'Transmitter setup,'
    with instructions for configuring transmitter channels. Detailed
    channel mappings were introduced for Radiomaster MT12, Radiomaster
    Pocket, and Flysky FS-i6. This update aims to provide clearer
    guidelines for users setting up their transmitters, while also
    offering comprehensive instructions for project setup and build
    process.
2025-07-18 fix: Add adjustable debug state to reduce log frequency
    Introduced `DEBUG_DELAY` to manage the frequency of debug messages.
    The debug state variable `debug_state` is incremented in each loop
    iteration.
    ```cpp
    //...
    int debug_state = 0;
    //...
    //...
    if (debug_state >= DEBUG_DELAY)
    debug_state = 0;
    ```
    This change reduces the load on the serial output, helping maintain
    performance on the AVR Nano Every when debugging is enabled. The
    debugging condition is checked before printing, allowing debug
    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
    [rcfw.ino]
2025-07-18 feat: Adjust control configuration for improved handling
    Updated the definition of SPEED_CHANNEL for RADIOMASTER_PG to use
    channel 6 instead of 5, as channel 5 issues were causing it to
    act like a switch rather than a potentiometer, affecting control
    precision.
    Enhanced the `controls` function across multiple models (`NOTANK`,
    `RC_BENCHY`, `SNOW_MOBILE`) to accept an additional parameter
    `throttle_max` to incorporate better handling through improved
    speed mapping. The throttle range is now mapped from 45 to 135,
    facilitating smoother controls and reducing the likelihood of
    hitting low-speed cutoff in sensitive track maneuvers.
    In the `loop` section, replaced `pwm_max_raw` with `throttle_ma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
    [rcfw.ino]
2025-07-19 feat: Implement power cycling and watchdog for stability
    This commit introduces power cycling the receiver via a new POWER_PIN
    defined as A7. This allows for easier switching of controllers without
    manual intervention, particularly with ELRS receivers and bind phrases.
    Additionally, a watchdog timer (WDT) is enabled to reset the Arduino in
    case the system becomes unresponsive, enhancing stability.
    For the TX_CRSF protocol, a new LINK_DOWN_DELAY is introduced. The loop
    checks if the link is down for this specified delay and executes a
    5-second delay before resetting. This helps manage features specific
    to the CRSF protocol for detecting link loss.
    The `setup` function is updated to initial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
    [rcfw.ino]
2025-07-22 fix: Correct channel mapping configuration
    Update README.org to clarify channel configuration for ELRS,
    ensuring accurate potentiometer and switch mappings. Specifically,
    describe the correct setup for Radiomaster units including expansion
    modules, correcting the previous misconfiguration of channel 5.
    In rcfw.ino, fix the IGNITION_CHANNEL definition for Radiomaster
    transmitters by combining conditions for RADIOMASTER_ST and
    RADIOMASTER_PG to use IGNITION_CHANNEL 5 consistently,
    removing outdated conditional mapping for channel 9.
    [rcfw.ino]
2025-07-22 refactor: Simplify transmitter channel handling
    Refactor transmitter channel handling by introducing a new struct
    'channel_mapping' to encapsulate related channel information, and
    streamline channel configuration for different types of transmitters.
    Replace individual channel defines with a mapping function to obtain
    a default or specific transmitter's channel setup. This reduces
    repetitive logic and allows for cleaner and more maintainable code.
    - Defined 'channel_mapping' struct containing control, ignition,
    effect, and speed channels.
    - Created default and transmitter-specific mappings.
    - Updated logic in 'setup_controls' and 'loop' functions to use the
    structured mappings instead o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
    [rcfw.ino]
2025-07-22 feat: Enhance transmitter type detection
    Changed the TX_TYPE definition to RADIOMASTER, enhancing flexibility
    in distinguishing between different transmitter models. Implemented
    runtime detection for remote control types by examining channel 4's
    value during setup. This change determines which transmitter is
    connected and sets the `current_tx` variable accordingly. A debug
    output was added to assist in verifying the active transmitter,
    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
2025-07-22 refactor: Support variable-length LED arrays
    Modified the LED handling to accommodate variable-length LED arrays
    by introducing an end-of-array marker, -1. This allows for flexibility
    in different model configurations. Updated the LED definitions by
    adding -1 as an end marker.
    Refactored the set_led function to iterate over the LED array until
    the end marker is encountered. This enhances usability for models
    with different LED requirements. Introduced a helper function,
    setup_led, to initialize all LEDs in an array, replacing
    individual pinMode calls.
    These changes eliminate the assumption of fixed-size arrays, making
    the system more adaptable to future LED configurations and ensuring
    cons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
    [rcfw.ino]
2025-07-22 refactor: Remove unused failsafe code
    Remove the unused failsafe_channel declaration and related
    conditional failsafe code in the loop function. These elements
    were not being utilized in the current implementation for either
    IBus or CRSF protocols, making this code redundant.
    Originally this was part of an attempt at implementing a failsafe for
    receivers not properly supporting it - but never quite worked. ELRS
    receivers should always be able to do proper failsafe handling on
    receiver side, so use one of those if you need it.
    [rcfw.ino]
2025-07-27 fix: Address power pin and LED handling issues
    This commit resolves issues with power pin definitions and LED
    handling during setup and CRSF transmitter initialization. Key
    changes include:
    1. **Power Pin Definitions**:
    - Added a new `POWER_PIN_RCV` for enhanced control.
    - Changed `POWER_PIN` from `A7` to `A6`.
    2. **LED Setup and Initialization**:
    - Implemented a visual cue by toggling `power_leds`,
    `effect_leds`, and `front_leds` on setup to indicate
    successful start-up.
    - Added proper initialization for `POWER_PIN_RCV` to ensure its
    state is correctly set at the start.
    3. **Watchdog Timer Reset Delay Function**:
    - Introduced `wdt_reset_delay(int d)` to hand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
    [rcfw.ino]
2025-07-28 fix: Adjust LED initialization and control behavior
    Refactor LED array management and correct LED control behavior in
    initialization phase. The `POWER_LEDS` and `FRONT_LEDS` definitions have
    been modified to improve clarity and correct assignments appropriate to
    the `NOTANK` model condition. The redundant incrementation of the index
    variable `i` has been removed and consolidated within loops in `set_led`
    and `setup_led`.
    In `setup`, initial LED activation now refrains from immediate
    deactivation, replaced by a longer delay ensuring systems are settled
    before switching LEDs off. Additionally, a corrective LED activation
    call is added in the main loop to better reflect the front LED state
    ali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
    [rcfw.ino]
2025-08-17 feat: Support multiple UART speeds for Nano boards
    Updated README to clarify the differences between the Arduino
    Nano Every and the original Nano, highlighting their UART
    capabilities and price differences. The original Nano now has
    automatic UART speed adjustments with CRSF_SPEED set to 115200
    and other boards retaining 420000 as default for reliability.
    In rcfw.ino, added a preprocessor directive to set CRSF_SPEED
    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
2025-08-17 docs: Revise README for LED and receiver configurations
    Reorganized and expanded the README to include clear sections and
    instructions related to LED groups and ELRS receiver reset, clarifying
    wiring details and use cases.
    - Added separate sections for LED groups and ELRS receiver reset
    - Updated descriptions for default LED pins and configurations
    - Emphasized the importance of visible status LEDs for safety
    - Detailed use of transistors for power management of LEDs and receivers
    - Clarified Arduino pin configurations and usage with NPN transistors
    - Deprecated hardware-only LED setup section, integrating it into
    the LED groups section
    These changes ensure the documentation reflects cur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
2025-08-17 fix: Correct typo in throttle_channel initialization
    Corrected a typo in the `throttle_channel` variable initialization
    within the `setup_controls` function. The previous code incorrectly
    spelled it as `throttle_thannel`. This typo could cause runtime
    errors or unexpected behavior during control setup. By fixing
    the typo, we ensure `throttle_channel` is properly assigned
    when `controls` is set to `RX_MAX`.
    [rcfw.ino]
2026-06-04 Add Arduino shield schematics and documentation
    [arduino-nano-shield.kicad_pcb, arduino-nano-shield.kicad_sch]
2026-06-04 Add V2 board
    - jumper for powering second ESC header VCC from main VCC net
    - GPS header with D5/D6
    - support two servos on servo header
    [arduino-nano-shield.kicad_pcb, arduino-nano-shield.kicad_sch]
2026-06-08 Add v2.1 board
    - add three pin header as alternative for LED connections (populate
    with angled header) to connect to various multiplexing controllers
    - add headers for A20 and A21 as aux connectors
    [arduino-nano-shield.kicad_pcb, arduino-nano-shield.kicad_sch]
2026-06-11 Add support for LED multiplexing via 74HC595D
2026-06-11 Add Makefile for building, using arduino-cli
2026-06-11 Fix build for Flysky remotes
    [rcfw.ino]
